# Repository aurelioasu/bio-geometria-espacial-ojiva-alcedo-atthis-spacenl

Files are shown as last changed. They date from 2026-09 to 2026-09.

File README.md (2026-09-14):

<p align="center">
  
  
</p>

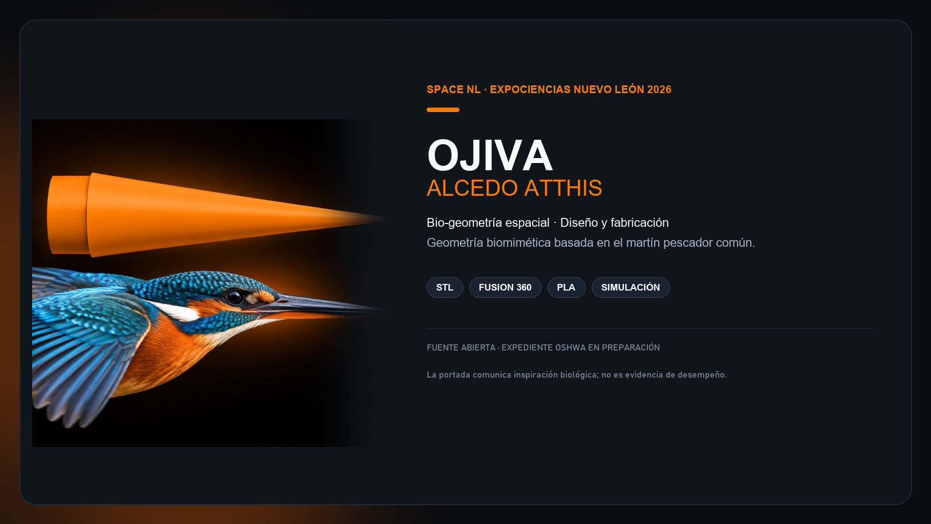
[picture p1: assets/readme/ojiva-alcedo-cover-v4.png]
Alcedo atthis cover comparing the released STL nose cone and the clearly visible kingfisher beak


Open hardware research project by SpaceNL for a biomimetic experimental-rocketry nose cone inspired by the streamlined beak morphology of the common kingfisher (*Alcedo atthis*).

> **Research prototype v1.0.** The project is prepared for OSHWA self-certification, but is **not certified** and has no OSHWA UID. Do not use the OSHWA certification mark unless and until an official UID is issued.

## Explore the project

| Area | Contents | Start here |
| --- | --- | --- |
| CAD and fabrication | Native Fusion 360 source plus printable STL | [`cad/`](cad/) |
| Manufacturing | BOM, print controls, fit and safety notes | [`docs/manufacturing/`](docs/manufacturing/) |
| Structural evidence | Fusion 360 screenshots with interpretation limits | [`docs/simulation/`](docs/simulation/) |
| Research record | Editable DOCX and reference PDF | [`docs/research/`](docs/research/) |
| Open-hardware record | Licensing, checklist and release information | [`docs/oshwa/`](docs/oshwa/) |

## Version snapshot

- Biomimetic nose cone geometry with an integrated coupling base.
- Native source: Autodesk Fusion 360 (`.f3d`).
- Manufacturing mesh: binary STL with 12,948 triangles.
- Measured STL envelope: approximately 50.47 x 52.10 x 200.00 mm.
- Documented prototype material: PLA, using 1.75 mm filament.
- Published, immutable Git revision: [`v1.1.6`](https://github.com/aurelioasu/bio-geometria-espacial-ojiva-alcedo-atthis-spacenl/tree/v1.1.6).

> **Configuration control.** The source report describes a 134.5 mm-long prototype with a 50.2 mm base, whereas the published STL has a 200 mm envelope length. This is unresolved. Confirm the intended CAD revision and units in Fusion 360 or the slicer before fabrication, testing, or certification.

## What this does and does not validate

The research records preliminary structural results and geometric continuity. It does not provide a reproducible, quantitative drag-coefficient comparison, CFD case, wind-tunnel measurement, or instrumented flight dataset that supports a performance claim relative to a conventional nose cone. Read [the preliminary-results note](docs/simulation/RESULTADOS_PRELIMINARES.md) before reusing any performance statement.

This is an experimental research component, not a flight-certified part or a propulsion guide. Any integration, testing, and operation must follow applicable rules and be reviewed for full-vehicle stability, recovery, retention and safety.

## Build from source

1. Inspect [`ojiva-alcedo-atthis-v1.f3d`](cad/native/ojiva-alcedo-atthis-v1.f3d) and confirm revision and units.
2. Import the [STL](cad/mesh/ojiva-alcedo-atthis-v1.stl) in millimetres; measure length and base diameter before printing.
3. Follow the [manufacturing guide](docs/manufacturing/BUILD.md) and record the print configuration.
4. Publish modified designs with their editable source and validation evidence.

## Licensing and attribution

- Hardware and design files: [CERN-OHL-W-2.0](LICENSES_CERN-OHL-W-2.0.txt).
- Original documentation and media: [CC-BY-SA-4.0](LICENSES_CC-BY-SA-4.0.txt).
- Scope by folder and branding exclusions: [LICENSE.md](LICENSE.md).

## Contributing

Contributions must preserve the editable source, version traceability, reproducible instructions and verifiable results. See [CONTRIBUTING.md](CONTRIBUTING.md).

## Team

Original research developed by:

- Suri Paola Frausto Galindo
- America Aidee Segovia Martinez

Advisor:

- Fernando Alonso Villalobos

Open documentation: SpaceNL.

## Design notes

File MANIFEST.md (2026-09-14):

# Manifiesto de contenido v1.0.0

Este manifiesto identifica los archivos primarios publicados en la etiqueta `v1.0.0`. Las sumas SHA-256 permiten verificar que un archivo descargado coincide con el material liberado.

| Archivo | Funcion | SHA-256 |
| --- | --- | --- |
| `cad/native/ojiva-alcedo-atthis-v1.f3d` | Fuente CAD editable de Fusion 360 | `D543FB4C9E730A3A1D716B9463678485CB1BFE820173DCD3D1CA67A85CF4340A` |
| `cad/mesh/ojiva-alcedo-atthis-v1.stl` | Malla de fabricacion | `6E9F03CEE8F1E21AC221341520479F85B44CF039933307206C8FF70E3EA332F6` |
| `docs/research/Ojiva_documento_2.docx` | Documento de investigacion editable | `803769521D18508F5E9D0B400104D99B706338AE7FFE21C1CF63B48623F596D7` |
| `docs/research/Ojiva_documento_2.pdf` | Version de referencia del documento de investigacion | `2F34BB4639A58B46B4553D86C699F0A6A4898D5983D856D7505999AA737838E5` |

Las ocho capturas de Fusion 360 se conservan en `media/simulation/`. Consulte `docs/simulation/RESULTADOS_PRELIMINARES.md` para sus condiciones y limites de interpretacion.

## Exclusiones conocidas

- No se incluyeron motores, propulsantes, firmware, componentes electronicos ni instrucciones de lanzamiento.
- No se proporcionaron los archivos de estudio de Fusion 360, configuraciones de laminador, datos CFD, mallas de fluido, datos de tunel de viento ni telemetria de vuelo.
- El STL no contiene unidades y su longitud de envolvente difiere de la dimension citada por el documento. Esta diferencia se documenta como pendiente antes de una validacion de fabricacion o una solicitud OSHWA.

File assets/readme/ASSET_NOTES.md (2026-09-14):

# README assets

- `ojiva-alcedo-hero.png`: editorial illustration for the repository header. It is illustrative only and does not replace the CAD files or constitute aerodynamic evidence.
- `ojiva-alcedo-hero-v2.png`: README header artwork. Its ojiva form is based on a direct render of the released STL and is composed parallel to a flying *Alcedo atthis* beak to communicate the biological inspiration. The bird and artwork are illustrative context, not technical or aerodynamic evidence.
- `ojiva-alcedo-cover-v3.png`: final README cover layout, pairing the v2 source visual with project title and descriptive context. It is illustrative and does not replace the released CAD/STL or constitute technical evidence.
- `ojiva-alcedo-hero-v3.png`: source visual with an enlarged *Alcedo atthis* head and beak aligned below the published STL form; illustrative only.
- `ojiva-alcedo-cover-v4.png`: current README cover layout built from the v3 visual so the ojiva and kingfisher beak remain legible at README size; illustrative only.
- `ojiva-alcedo-icon.png`: original project icon retained as repository media; it is no longer displayed in the README header.

Both assets are original project documentation media and are released under CC-BY-SA-4.0, as specified in the repository [LICENSE](../../LICENSE.md).

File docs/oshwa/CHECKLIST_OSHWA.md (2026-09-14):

# Expediente de autocertificacion OSHWA

**Producto:** Ojiva biomimetica Alcedo atthis v1.0  
**Titular previsto:** SpaceNL  
**Estado:** listo para revision del titular; no enviado y no certificado.

## Checklist de publicacion

- [x] Archivo fuente editable: `cad/native/ojiva-alcedo-atthis-v1.f3d`.
- [x] Archivo auxiliar de fabricacion: `cad/mesh/ojiva-alcedo-atthis-v1.stl`.
- [x] Lista de materiales y guia de fabricacion.
- [x] Documentacion y evidencia de simulacion publicada con limites claros.
- [x] Licencia de hardware abierta: CERN-OHL-W-2.0.
- [x] Licencia de documentacion abierta: CC-BY-SA-4.0.
- [x] Version identificada: v1.0.
- [ ] Confirmacion del titular de derechos y de que puede liberar CAD, STL, texto e imagenes.
- [ ] Resolucion de la discrepancia de longitud 134.5 mm frente a 200 mm del STL.
- [ ] Confirmacion de que no faltan archivos auxiliares bajo control del titular (ensamble, dibujos, configuraciones de impresion o estudios de Fusion 360).
- [x] URL publica definitiva: `https://github.com/aurelioasu/bio-geometria-espacial-ojiva-alcedo-atthis-spacenl`.
- [x] Revision inmutable publicada: etiqueta Git `v1.1.6`.
- [ ] Datos de la persona/entidad certificante, correo de contacto y pais para el formulario.
- [ ] Revision de marca: no incluir logotipo OSHWA antes del UID.
- [ ] Envio de la solicitud y aceptacion del acuerdo de licencia de marca OSHWA por una persona autorizada.

## Datos para el formulario

| Campo | Valor propuesto / pendiente |
| --- | --- |
| Nombre del proyecto | Bio-geometria espacial: Diseno y fabricacion de ojiva Alcedo atthis |
| Version | 1.0 |
| Tipo | Componente aeroespacial experimental impreso en 3D |
| Categoria sugerida | Aerospace / 3D printing, segun opciones vigentes del formulario |
| Sitio de documentacion | https://github.com/aurelioasu/bio-geometria-espacial-ojiva-alcedo-atthis-spacenl |
| Hardware | CERN-OHL-W-2.0 |
| Software | No aplica: no se libera firmware ni software de operacion |
| Documentacion | CC-BY-SA-4.0 |
| Pais / contacto | Pendiente de confirmar por titular |

## Condiciones OSHWA aplicadas

La documentacion se ha organizado para que las contribuciones controladas por el titular sean publicas, modificables y distribuibles. OSHWA requiere que el producto, sus propios disenos y su documentacion se compartan abiertamente; la autocertificacion se presenta en linea y, si se aprueba, recibe un UID por version. Consulte las fuentes oficiales antes del envio:

- https://certification.oshwa.org/requirements.html
- https://certification.oshwa.org/process/hardware.html
- https://certification.oshwa.org/process/documentation.html

Este checklist no es asesoria legal ni una certificacion.

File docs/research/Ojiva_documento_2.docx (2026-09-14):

ExpoCiencias Estatal 2026
Nuevo León

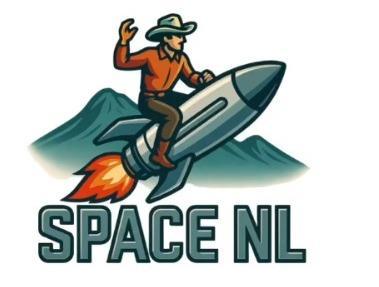
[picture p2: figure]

ExpoCNL-S-CE-175

Bio-geometría espacial, Diseño y fabricación de ojiva Alcedo atthis

Nombre Autor 1: Suri Paola Frausto Galindo
Nombre Autor 2: America Aidee Segovia Martínez

Nombre Asesor: Fernando Alonso Villalobos

Área: Ciencias Espaciales, CE

Categoría: Superior, S

Objetivos de Desarrollo Sostenible que abona el proyecto

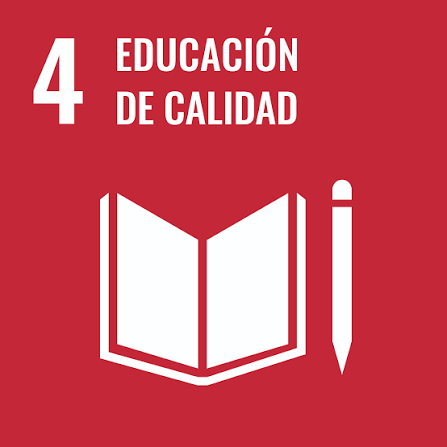
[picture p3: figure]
Objetivo de Desarrollo Sostenible 4 - Wikipedia, la enciclopedia libre
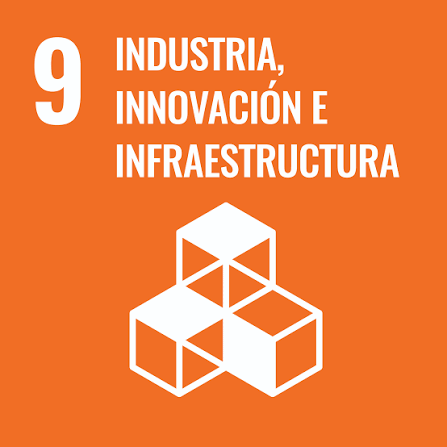
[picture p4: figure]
Objetivo de Desarrollo Sostenible 9 - Wikipedia, la enciclopedia libre
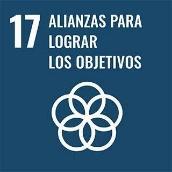
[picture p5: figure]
ODS 17 Alianzas para lograr los objetivos | Pacto Mundial ONU

Monterrey, Nuevo León, a 4 de agosto de 2026

NOMBRE DE PROYECTO

Autores: Frausto, S. P.; Segovia, A. A.

RESUMEN

El presente proyecto de investigación tiene como propósito diseñar y analizar una ojiva biomimética inspirada en la morfología del pico del Martín pescador (Alcedo atthis) para su aplicación en cohetería experimental de baja y media potencia. La investigación surge ante la necesidad de explorar alternativas aerodinámicas innovadoras que permitan disminuir el coeficiente de arrastre y optimizar el desempeño de vuelo de cohetes experimentales mediante principios bio-inspirados. El estudio integra fundamentos de biomimética, aerodinámica subsónica, modelado CAD y manufactura digital. La metodología implementada incluyó investigación documental especializada, análisis biomorfológico del pico del Martín pescador, diseño tridimensional mediante Autodesk Fusion 360, análisis estructural y fabricación de prototipos utilizando impresión 3D en PLA. Los resultados preliminares evidenciaron una adecuada continuidad geométrica, reducción potencial de perturbaciones aerodinámicas y un comportamiento estructural favorable bajo análisis estático y modal. Asimismo, el rediseño iterativo permitió optimizar la unión entre la ojiva y el fuselaje, incrementando la resistencia mecánica del sistema. La propuesta representa una contribución innovadora al estudio de soluciones biomiméticas aplicadas a la ingeniería aeroespacial experimental y fortalece el desarrollo de proyectos STEM vinculados con ciencias espaciales y tecnologías emergentes.

Palabras clave: biomimética, cohetería experimental, aerodinámica, ojiva, impresión 3D.

ABSTRACT

This research project aims to design and analyze a biomimetic nose cone inspired by the morphology of the kingfisher’s beak (Alcedo atthis) for its application in low- and medium-power experimental rocketry. The research emerged from the need to explore innovative aerodynamic alternatives capable of reducing drag coefficient and optimizing the flight performance of experimental rockets through bio-inspired principles. The study integrates foundations of biomimetics, subsonic aerodynamics, CAD modeling, and digital manufacturing. The implemented methodology included specialized documentary research, biomorphological analysis of the kingfisher’s beak, three-dimensional design using Autodesk Fusion 360, structural analysis, and prototype fabrication through PLA 3D printing. Preliminary results demonstrated adequate geometric continuity, potential reduction of aerodynamic disturbances, and favorable structural behavior under static and modal analysis. Furthermore, the iterative redesign process optimized the connection between the nose cone and the rocket fuselage, increasing the mechanical resistance of the system. The proposal represents an innovative contribution to the study of biomimetic solutions applied to experimental aerospace engineering and strengthens the development of STEM projects related to space sciences and emerging technologies.

Keywords: biomimetics, experimental rocketry, aerodynamics, nose cone, 3D printing.

LISTA DE ILUSTRACIONES, GRÁFICOS Y TABLAS

Imagen 1: Primeros bocetos de la ojiva biomimética 17

Imagen 2: Análisis de tensión estática, desplazamiento 17

Imagen 3: Análisis de frecuencias modales 18

Imagen 4: Análisis de deformación mecánica 18

Imagen 5: Impresión 3D del primer prototipo 18

Imagen 6: Mejoramiento de la base, nuevo diseño 19

Imagen 7: Ajuste de la punta, nuevo diseño 19

Imagen 8: Segundo prototipo terminado 19

LISTA DE SIGLAS

APA – American Psychological Association

CAD – Computer-Aided Design (Diseño Asistido por Computadora)

CFD – Computational Fluid Dynamics (Dinámica de Fluidos Computacional)

Cd – Coeficiente de Arrastre Aerodinámico

FDM – Fused Deposition Modeling (Modelado por Deposición Fundida)

IA – Inteligencia Artificial

NASA – National Aeronautics and Space Administration

PETG – Polyethylene Terephthalate Glycol (Tereftalato de Polietileno Glicol)

PLA – Polylactic Acid (Ácido Poliláctico)

SLA – Stereolithography Apparatus (Estereolitografía)

SPLINE -- Función matemática compuesta por varios polinomios unidos entre sí, utilizada para crear curvas suaves y continuas.

STEM – Science, Technology, Engineering and Mathematics (Ciencia, Tecnología, Ingeniería y Matemáticas).

STL – Standard Triangle Language / STereoLithography File

STEP – Standard for the Exchange of Product Model Data

3D – Tridimensional

Mach – Relación entre la velocidad de un objeto y la velocidad del sonido en el medio fluido correspondiente.

ÍNDICE

INTRODUCCIÓN ………………………………………………………………..…………………………...7

PLANTEAMIENTO DEL PROBLEMA………………………………………………….…………….…….8

ESTADO DE LA TÉCNICA ……………………………..…………………………………………………...9

JUSTIFICACIÓN ……………………………………..………………………………………………….….12

HIPÓTESIS O META DE INGENIERÍA ……………………………..…………………………………….14

OBJETIVOS ………………………………………………………………………..………………………..14

PROCESO METODOLÓGICO………………………………………………………………..…………….15

RESULTADOS ………………………………………………………………………………………………17

DISCUSION………………………………………………………………………………………………….19

CONCLUSIONES …………………………………………………………………………………………...20

FUTURAS LÍNEAS DE INVESTIGACIÓN………………………………………………………………...21

LITERATURA CONSULTADA……………………………………………………………………………...22 ANEXOS……………………………………………………………………………………………………...24

1. INTRODUCCIÓN

La exploración aeroespacial ha impulsado históricamente importantes avances científicos y tecnológicos en áreas como la ingeniería aeronáutica, la dinámica de fluidos, los materiales avanzados y la manufactura de precisión. Dentro de este contexto, la cohetería experimental de baja y media potencia se ha consolidado como una plataforma de investigación aplicada que permite analizar fenómenos aerodinámicos reales mediante el diseño, construcción y validación de vehículos experimentales a escala reducida.

Uno de los principales retos en el diseño de cohetes experimentales consiste en optimizar su desempeño aerodinámico, particularmente durante la fase de ascenso atmosférico. La resistencia aerodinámica generada por la interacción entre el vehículo y el flujo de aire representa una de las principales limitantes para alcanzar mayores altitudes y mejorar la eficiencia energética del sistema propulsivo. De acuerdo con Anderson (2016), la geometría externa del vehículo influye directamente en la distribución de presiones, el comportamiento de la capa límite y la formación de turbulencias.

Dentro de los componentes aerodinámicos del cohete, la ojiva desempeña un papel fundamental debido a que constituye la primera superficie en contacto con el flujo de aire. Diseños geométricos inadecuados pueden provocar separación prematura del flujo, incremento del arrastre y pérdida de estabilidad longitudinal (Barrowman, 1967). Por esta razón, el desarrollo de geometrías optimizadas representa una línea de investigación relevante dentro de la ingeniería aeroespacial experimental.

En años recientes, la biomimética ha emergido como una disciplina innovadora orientada a resolver problemas tecnológicos mediante la observación y adaptación de soluciones presentes en la naturaleza. Según Benyus (2002), los organismos biológicos representan modelos altamente eficientes desarrollados a través de millones de años de evolución, cuyas características pueden transferirse a sistemas de ingeniería contemporánea.

Uno de los ejemplos más representativos de biomimética aplicada al transporte corresponde al rediseño del tren bala Shinkansen Serie 500 en Japón. El ingeniero japonés Eiji Nakatsu utilizó como referencia la morfología del pico del Martín pescador para reducir el boom sónico y optimizar el desempeño aerodinámico del sistema ferroviario, logrando además disminuir el consumo energético del vehículo (Nakatsu, 2009).

A partir de este antecedente, la presente investigación propone el diseño y análisis de una ojiva biomimética inspirada en la geometría del pico del Martín pescador (Alcedo atthis), orientada a cohetería experimental de baja y media potencia. El proyecto integra principios de biomimética, aerodinámica subsónica, diseño CAD y manufactura digital mediante impresión 3D, buscando desarrollar una alternativa geométrica capaz de disminuir el coeficiente de arrastre aerodinámico respecto a configuraciones convencionales.

La investigación adopta un enfoque tecnológico-aplicado y descriptivo-comparativo, incorporando modelado tridimensional, análisis estructural y evaluación geométrica preliminar. Asimismo, se contemplan futuras etapas relacionadas con simulaciones CFD, pruebas experimentales y vuelos instrumentados que permitan validar cuantitativamente el desempeño aerodinámico de la propuesta.

Además de su relevancia científica y tecnológica, el proyecto posee un importante valor educativo y formativo, debido a que promueve el aprendizaje interdisciplinario en áreas STEM mediante experiencias reales de diseño aeroespacial experimental. La integración de biomimética y cohetería favorece procesos de innovación, creatividad tecnológica y divulgación científica orientados al fortalecimiento de vocaciones en ingeniería y ciencias espaciales.

2. PLANTEAMIENTO DEL PROBLEMA

La cohetería experimental de baja y media potencia constituye un campo de investigación tecnológica donde el desempeño aerodinámico del vehículo determina en gran medida la eficiencia, estabilidad y seguridad del vuelo. Durante la fase de ascenso, un cohete está sometido a múltiples fuerzas aerodinámicas, siendo la resistencia del aire una de las principales limitantes para alcanzar mayores altitudes y mantener trayectorias estables.

En términos físicos, el arrastre aerodinámico se produce debido a la interacción entre el flujo de aire y la superficie externa del cohete. Este fenómeno depende directamente de factores como la velocidad, rugosidad superficial, área frontal, densidad del aire y geometría del vehículo. Diversos estudios en dinámica de fluidos establecen que la geometría frontal del sistema desempeña un papel crítico en la formación de turbulencias, distribución de presión y comportamiento de la capa límite (Anderson, 2017).

Dentro de los componentes estructurales del cohete, la ojiva es el elemento que inicialmente entra en contacto con el flujo de aire, razón por la cual su diseño influye significativamente en el coeficiente de arrastre (Cd). Una ojiva ineficiente puede generar separación prematura del flujo, incremento de turbulencia y mayores pérdidas de energía aerodinámica, afectando directamente el rendimiento del vehículo (Barrowman, 1967).

En la mayoría de los proyectos educativos y de cohetería experimental amateur, los diseños de ojivas se limitan a configuraciones geométricas tradicionales como:

- Ojiva cónica.
- Ojiva parabólica.
- Ojiva elíptica.
- Ojiva ojival tangente.

Estas geometrías han demostrado funcionalidad aceptable debido a su simplicidad de fabricación y comportamiento aerodinámico conocido. Sin embargo, gran parte de estas configuraciones fueron originalmente desarrolladas para contextos aeronáuticos y balísticos convencionales, sin explorar ampliamente alternativas derivadas de principios biomiméticos.

Paralelamente, la biomimética ha emergido como un área de innovación científica capaz de transferir soluciones naturales a problemas tecnológicos complejos. Diversas investigaciones han demostrado que organismos biológicos poseen configuraciones morfológicas altamente optimizadas para desplazarse eficientemente en medios fluidos, reduciendo turbulencia y consumo energético (Benyus, 2002).

Uno de los casos más relevantes es el del Martín pescador, ave cuya geometría craneal le permite penetrar el agua prácticamente sin generar perturbaciones significativas. El estudio de esta morfología condujo al rediseño del tren bala Shinkansen Serie 500 en Japón, logrando mejoras aerodinámicas y energéticas comprobadas (Nakatsu, 2009).

A pesar de estos antecedentes exitosos en transporte ferroviario y biomimética aplicada, existe una limitada evidencia científica acerca de la implementación de perfiles bio-inspirados en cohetería experimental subsónica. Particularmente, no se dispone de suficiente información experimental o computacional que permita determinar si una ojiva inspirada en el pico del Martín pescador puede reducir el coeficiente de arrastre y mejorar el comportamiento aerodinámico de un cohete experimental de baja y media potencia.

Además, dentro del ámbito educativo y de divulgación aeroespacial, existe una necesidad creciente de desarrollar proyectos que no solamente reproduzcan diseños convencionales, sino que promuevan innovación tecnológica, investigación aplicada y pensamiento ingenieril avanzado. La ausencia de estudios de biomimética aplicada a cohetería experimental limita el desarrollo de nuevas soluciones aerodinámicas y restringe las posibilidades de innovación dentro de la formación científica juvenil.

Por ello, la presente investigación busca analizar si la geometría bio-inspirada basada en el pico del Martín pescador puede constituir una alternativa funcional y aerodinámicamente eficiente frente a las ojivas tradicionales utilizadas en cohetería experimental.

A partir de esta problemática se formula la siguiente pregunta de investigación:

¿La implementación de una ojiva bio-inspirada en la morfología del pico del Martín pescador permite disminuir el coeficiente de arrastre aerodinámico y mejorar el desempeño de vuelo de un cohete experimental de baja y media potencia en comparación con ojivas convencionales?

La respuesta a esta interrogante permitirá generar conocimiento aplicable al diseño aeroespacial experimental, ampliar el campo de estudio de la biomimética aplicada y establecer bases metodológicas para futuros desarrollos en aerodinámica bio-inspirada.

3. ESTADO DE LA TÉCNICA

## El Desarrollo de la cohetería experimental en México.

En México, el crecimiento del sector aeroespacial ha impulsado el interés por el desarrollo de proyectos de cohetería experimental tanto en el ámbito universitario como en niveles educativos medios y superiores. La Agencia Espacial Mexicana ha promovido iniciativas relacionadas con divulgación científica, investigación tecnológica y formación de capital humano especializado en ciencias espaciales.

Instituciones como el Instituto Politécnico Nacional, la Universidad Nacional Autónoma de México y el Tecnológico de Monterrey han desarrollado investigaciones orientadas al diseño de sistemas de navegación, telemetría y control para vehículos experimentales y nanosatélites educativos.

El fortalecimiento de competencias aeroespaciales en México también ha sido impulsado mediante competencias nacionales e internacionales de ingeniería experimental, donde estudiantes desarrollan habilidades relacionadas con programación, electrónica, simulación computacional y manufactura digital.

Desde la perspectiva educativa, la integración de la cohetería experimental en entornos MakerSpace ha permitido implementar experiencias de aprendizaje interdisciplinarias basadas en el construccionismo y la cultura Maker. En este sentido, la construcción física de prototipos tecnológicos promueve creatividad, experimentación e innovación en los estudiantes (Blikstein, 2013).

De forma complementaria, los MakerSpaces educativos representan entornos altamente efectivos para el aprendizaje experiencial, debido a que integran resolución de problemas reales, diseño colaborativo y pensamiento de ingeniería (Martin, 2015).

En este contexto, la cohetería experimental se convierte en una herramienta pedagógica alineada con los Objetivos de Desarrollo Sostenible, particularmente el ODS 4 “Educación de Calidad” y el ODS 9 “Industria, Innovación e Infraestructura”, promoviendo la alfabetización científica y tecnológica en estudiantes.

La UNESCO señala que las competencias digitales avanzadas y el pensamiento tecnológico son indispensables para afrontar los retos educativos y científicos contemporáneos (UNESCO, 2021). Paralelamente, la OECD establece que la alfabetización tecnológica constituye una competencia estratégica para el desarrollo económico y científico de las nuevas generaciones (OECD, 2023).

## Componentes principales de un cohete experimental

Un cohete experimental se encuentra conformado por diversos sistemas estructurales, mecánicos y electrónicos que trabajan de manera integrada para garantizar estabilidad, seguridad y funcionalidad durante el vuelo.

Los componentes fundamentales incluyen:

- Nariz aerodinámica u ojiva.
- Fuselaje principal.
- Sistema de propulsión.
- Aletas estabilizadoras.
- Sistema de recuperación.
- Compartimiento electrónico.
- Sistema de telemetría.
- Sistema de control y navegación.
- Sensores de monitoreo.
- Fuente de alimentación energética.

El diseño estructural y aerodinámico de un cohete debe garantizar un equilibrio adecuado entre estabilidad y eficiencia energética para optimizar el desempeño durante el ascenso (Sutton & Biblarz, 2017).

Las etapas generales de desarrollo y operación de un cohete experimental comprenden:

1. Diseño conceptual.
2. Modelado y simulación aerodinámica.
3. Diseño estructural.
4. Integración electrónica.
5. Programación del sistema de control.
6. Pruebas de validación.
7. Lanzamiento.
8. Telemetría y monitoreo.
9. Recuperación.
10. Análisis de datos post-vuelo.

Estas etapas responden a metodologías de ingeniería iterativa utilizadas en proyectos aeroespaciales contemporáneos, donde cada fase permite optimizar el desempeño del sistema y reducir riesgos operativos.

## Categorías y niveles de cohetería experimental

La cohetería experimental puede clasificarse de acuerdo con la potencia del motor, altitud alcanzada y complejidad tecnológica incorporada en el vehículo.

Cohetería de baja potencia: Emplea motores comerciales pequeños y sistemas básicos de estabilización. Generalmente es utilizada en procesos educativos introductorios orientados al aprendizaje de principios físicos fundamentales.

Cohetería de media potencia: Integra estructuras reforzadas y sistemas electrónicos de monitoreo, permitiendo vuelos más estables y controlados.

Cohetería de alta potencia: Utiliza sistemas avanzados de navegación, telemetría y recuperación automática. En este nivel suelen incorporarse algoritmos de control automático y redundancia electrónica para maximizar la seguridad operacional.

Cohetería científica experimental: Se enfoca en la recopilación de datos atmosféricos, validación de sensores y pruebas de tecnologías aeroespaciales emergentes.

El incremento de velocidad y altitud en vehículos experimentales exige diseños estructurales y aerodinámicos más complejos, especialmente en sistemas sometidos a condiciones supersónicas y variaciones extremas de presión atmosférica (Anderson, 2016).

## Cohetería experimental y aerodinámica subsónica

La cohetería experimental constituye una disciplina tecnológica enfocada en el diseño, construcción y evaluación de vehículos propulsados por reacción, empleados tanto con fines científicos como educativos. En el ámbito académico, la cohetería representa una herramienta altamente efectiva para el aprendizaje aplicado de conceptos relacionados con física, ingeniería mecánica, dinámica de fluidos y manufactura avanzada (Sutton & Biblarz, 2017).

Uno de los factores más relevantes en el desempeño de un cohete es su comportamiento aerodinámico. Durante el ascenso, el vehículo experimenta fuerzas de arrastre generadas por la interacción entre la superficie del cohete y el flujo de aire circundante. De acuerdo con Anderson (2017), el arrastre aerodinámico depende de variables como la velocidad, la densidad del aire, el área frontal y el coeficiente de arrastre (Cd), siendo este último altamente sensible a la geometría del vehículo.

La fuerza de arrastre puede representarse mediante la siguiente relación:

F_d =1/2ρv^2 C_d A

Donde:

- F_d representa la fuerza de arrastre.
- ρ corresponde a la densidad del aire.
- v es la velocidad del flujo.
- C_d es el coeficiente de arrastre.
- A representa el área frontal.

En cohetería experimental, la reducción del coeficiente de arrastre constituye un objetivo prioritario, ya que permite incrementar la eficiencia energética y mejorar la altitud alcanzada utilizando la misma cantidad de impulso propulsivo (Barrowman, 1967).

## Función aerodinámica de la ojiva

La ojiva es el componente frontal del cohete encargado de dividir inicialmente el flujo de aire durante el vuelo. Su diseño influye directamente en la formación de turbulencias, separación de flujo y estabilidad aerodinámica del sistema completo.

Según Niskanen (2013), las geometrías más utilizadas en cohetería experimental son:

- Ojiva cónica.
- Ojiva parabólica.
- Ojiva elíptica.
- Ojiva ojival tangente.
- Ojiva Von Kármán.

Cada configuración presenta ventajas específicas dependiendo del régimen de velocidad y de la misión del vehículo. Las ojivas cónicas ofrecen simplicidad de manufactura, mientras que las ojivas ojivales y Von Kármán presentan menores niveles de arrastre en regímenes transónicos y supersónicos.

Sin embargo, para velocidades subsónicas bajas y medias, la continuidad geométrica y la transición suave entre superficies representan factores fundamentales para minimizar pérdidas por turbulencia (Hoerner, 1965). Esto abre la posibilidad de explorar perfiles biomiméticos como alternativas funcionales a las geometrías tradicionales.

## Biomimética aplicada a la ingeniería

La biomimética es una disciplina interdisciplinaria que estudia modelos biológicos para resolver problemas tecnológicos y de ingeniería mediante principios inspirados en la naturaleza. Benyus (2002) sostiene que los organismos vivos representan soluciones optimizadas tras millones de años de evolución, por lo que su estudio puede conducir al desarrollo de tecnologías más eficientes y sostenibles.

En ingeniería aeroespacial y aeronáutica, diversos proyectos han empleado biomimética para reducir ruido, mejorar sustentación y disminuir resistencia aerodinámica. Fish y Battle (1995) demostraron que ciertas configuraciones biológicas pueden modificar favorablemente el comportamiento del flujo alrededor de superficies móviles. Asimismo, Wang et al. (2019) documentaron múltiples aplicaciones bio-inspiradas orientadas al control aerodinámico y aeroacústico.

Estas investigaciones respaldan la viabilidad científica de trasladar principios morfológicos biológicos al diseño de componentes aeroespaciales experimentales.

## El caso del Martín pescador y el Shinkansen

Uno de los ejemplos más reconocidos de biomimética aplicada al transporte corresponde al rediseño del tren bala japonés Shinkansen Serie 500. El ingeniero japonés Eiji Nakatsu observó que el Martín pescador podía ingresar al agua prácticamente sin generar salpicaduras debido a la geometría alargada y progresiva de su pico.

Inspirado en esta morfología, el frente del tren fue rediseñado para disminuir las ondas de presión generadas al salir de túneles. Como resultado, el sistema redujo el ruido aerodinámico, eliminó el boom sónico y disminuyó aproximadamente un 15% el consumo energético (Nakatsu, 2009).

Desde una perspectiva física, este comportamiento se explica por la transición gradual del flujo alrededor de superficies continuas, lo cual reduce perturbaciones y favorece una redistribución más uniforme de la presión dinámica.

La presente investigación retoma este antecedente como fundamento conceptual para trasladar principios biomiméticos al diseño de una ojiva para cohetería experimental.

## Modelado CAD y simulación computacional en ingeniería aeroespacial

Función Principal | Diseñar y representar piezas y vehículos aeroespaciales en 3D. | Analizar y predecir el comportamiento del flujo de aire.
Herramientas | Autodesk Fusion 360, SolidWorks, CATIA, entre otras. | Software y herramientas especializadas en CFD.
Aplicación | Creación de geometrías, prototipos y diseños paramétricos. | Evaluación aerodinámica y validación de diseños.
Ventaja | Permite modificar y optimizar el diseño antes de fabricarlo. | Permite detectar problemas aerodinámicos sin fabricar un prototipo físico.
Importancia | Facilita el desarrollo de prototipos y estructuras aeroespaciales complejas. | Reduce costos y tiempo al validar hipótesis aerodinámicas previamente.
Integración | Proporciona la geometría necesaria para realizar simulaciones. | Utiliza los modelos CAD para analizar su comportamiento aerodinámico.

En este proyecto, el modelado mediante splines y sólidos de revolución permite reproducir con precisión las curvas morfológicas del pico del Martín pescador y compararlas con geometrías convencionales bajo criterios geométricos y aerodinámicos.

4. JUSTIFICACIÓN

La exploración aeroespacial y el desarrollo de tecnologías asociadas a la ingeniería aeronáutica representan actualmente uno de los campos estratégicos más relevantes para el avance científico y tecnológico a nivel mundial. En este contexto, la cohetería experimental de baja y media potencia se ha consolidado como una plataforma formativa y de investigación aplicada que permite acercar a estudiantes e investigadores a principios reales de aerodinámica, propulsión, manufactura digital, simulación computacional y análisis estructural, favoreciendo el fortalecimiento de competencias STEM en áreas vinculadas con la industria aeroespacial.

Uno de los principales desafíos en el diseño de cohetes experimentales consiste en reducir las pérdidas aerodinámicas generadas durante la fase de ascenso. La resistencia del aire constituye una de las fuerzas que más limita el desempeño de un vehículo cohete, debido a que consume parte importante de la energía producida por el sistema propulsivo. De acuerdo con Anderson (2017), incluso pequeñas variaciones en la geometría frontal del vehículo pueden producir cambios significativos en el coeficiente de arrastre y, por consiguiente, en la eficiencia global del vuelo.

Dentro de este contexto, la ojiva representa el componente de mayor relevancia aerodinámica en la parte frontal del cohete, ya que es la primera superficie que interactúa con el flujo de aire. Diseños con discontinuidades geométricas o transiciones abruptas favorecen fenómenos de separación de capa límite y turbulencia, incrementando el arrastre y disminuyendo la estabilidad aerodinámica del sistema (Hoerner, 1965).

Aunque en la cohetería experimental predominan geometrías tradicionales como las ojivas cónicas, parabólicas y ojivales, la investigación sobre perfiles bio-inspirados continúa siendo limitada, particularmente en aplicaciones orientadas a cohetes de baja y media potencia. Esta ausencia de estudios representa una oportunidad de innovación tecnológica dentro del área de Ciencias Espaciales, especialmente considerando que la biomímetica ha demostrado ser una estrategia eficaz para resolver problemas complejos de ingeniería mediante la adaptación de soluciones presentes en organismos biológicos (Benyus, 2002).

La naturaleza ha optimizado durante millones de años estructuras altamente eficientes para desplazarse en medios fluidos. Uno de los casos más emblemáticos corresponde al Martín pescador (Alcedo atthis), cuya morfología craneal y, particularmente, la geometría de su pico, le permiten penetrar el agua con mínima perturbación superficial y baja resistencia hidrodinámica. Este principio fue aplicado exitosamente por el ingeniero japonés Eiji Nakatsu en el rediseño aerodinámico del tren bala Shinkansen Serie 500, logrando reducir el boom sónico y disminuir aproximadamente un 15% el consumo energético del sistema ferroviario (Nakatsu, 2009).

Tomando como referencia dicho antecedente, el presente proyecto propone trasladar principios biomiméticos al diseño de una ojiva para cohetería experimental, utilizando como inspiración el perfil geométrico del pico del Martín pescador. Esta propuesta resulta relevante porque integra conocimientos de aerodinámica, ingeniería aeroespacial, biomímetica, manufactura digital y simulación computacional, contribuyendo al desarrollo de soluciones tecnológicas innovadoras dentro del ámbito educativo y científico.

Asimismo, el proyecto posee pertinencia formativa y social, debido a que promueve el aprendizaje práctico de ingeniería aeroespacial mediante metodologías activas de investigación y desarrollo tecnológico. Desde una perspectiva STEM, el proyecto favorece la integración interdisciplinaria de matemáticas, física, diseño CAD, dinámica de fluidos y fabricación digital, incentivando vocaciones científicas en áreas aeroespaciales de alta especialización.

Adicionalmente, la investigación puede sentar bases metodológicas para futuros desarrollos en aerodinámica bio-inspirada aplicada a vehículos experimentales, drones, sistemas aeronáuticos y tecnologías aeroespaciales educativas. En consecuencia, la presente propuesta no solo representa una innovación dentro de la cohetería experimental, sino también una contribución potencial al estudio de soluciones biomiméticas aplicadas a la ingeniería del futuro.

5. HIPÓTESIS O META DE INGENIERÍA

Si se diseña una ojiva para cohetería experimental basada en la geometría morfológica del pico del Martín pescador, entonces el coeficiente de arrastre aerodinámico del cohete disminuirá respecto al presentado por ojivas convencionales de tipo cónico y ojival, debido a que la transición progresiva de su perfil geométrico favorecerá un flujo de aire más uniforme, reducirá la separación de la capa límite y disminuirá la generación de turbulencias durante la fase de ascenso en régimen subsónico.

Esta hipótesis se fundamenta en principios de dinámica de fluidos y biomimética aplicada, los cuales establecen que las superficies con continuidad geométrica y curvaturas graduales presentan menores pérdidas aerodinámicas en comparación con perfiles de transición abrupta (Hoerner, 1965). Asimismo, se sustenta en antecedentes de ingeniería bio-inspirada como el rediseño del tren Shinkansen Serie 500, donde la geometría inspirada en el pico del Martín pescador permitió reducir significativamente perturbaciones aerodinámicas y consumo energético (Nakatsu, 2009).

En consecuencia, se plantea que la implementación de una ojiva biomimética podría incrementar la eficiencia aerodinámica del vehículo, mejorar la estabilidad longitudinal y favorecer un mayor aprovechamiento del impulso propulsivo en cohetes experimentales de baja y media potencia.

6. OBJETIVOS

6.1. Objetivo general

Diseñar, modelar y evaluar aerodinámicamente una ojiva bio-inspirada basada en la morfología del pico del Martín pescador mediante herramientas CAD y análisis computacional, con el propósito de determinar su viabilidad como alternativa de menor resistencia aerodinámica frente a ojivas convencionales utilizadas en cohetería experimental de baja y media potencia.

6.2. Objetivos específicos

1. Analizar los principios de biomimética aplicada a la aerodinámica y estudiar las características morfológicas del pico del Martín pescador relacionadas con la reducción de resistencia en medios fluidos.
2. Identificar los parámetros geométricos y aerodinámicos más relevantes en el diseño de ojivas para cohetería experimental subsónica.
3. Diseñar modelos tridimensionales de una ojiva biomimética inspirada en el pico del Martín pescador utilizando Autodesk Fusion 360.
4. Desarrollar modelos comparativos de ojivas convencionales tipo cónica y ojival bajo las mismas condiciones geométricas de referencia.
5. Evaluar comparativamente las geometrías diseñadas considerando continuidad superficial, relación de finura, área frontal y potencial aerodinámico.
6. Preparar modelos digitales compatibles con futuras simulaciones CFD orientadas al cálculo del coeficiente de arrastre y visualización de líneas de flujo.
7. Establecer una metodología reproducible para el diseño y análisis de componentes aeroespaciales bio-inspirados aplicados a la cohetería experimental.
8. Generar bases técnicas y científicas para futuras pruebas experimentales mediante impresión 3D, túnel de viento y vuelos instrumentado.

6.3. Objetivos de Desarrollo Sostenible (ODS)

El proyecto de investigación enfocado en el diseño de una ojiva biomimética inspirada en el pico del Martín pescador posee una relación directa con diversos Objetivos de Desarrollo Sostenible (ODS) establecidos por la Organización de las Naciones Unidas dentro de la Agenda 2030, debido a que promueve la innovación tecnológica, el desarrollo científico, la educación STEM y la investigación aplicada en ingeniería aeroespacial.

A continuación, se describen los ODS con los que la propuesta guarda mayor vinculación:

ODS 4, Educación de calidad: El proyecto contribuye directamente al ODS 4, el cual busca garantizar una educación inclusiva, equitativa y de calidad, así como promover oportunidades de aprendizaje permanente para todos.

Este criterio aplica a personas o grupos que cuenten con acceso a dispositivos electrónicos, equipo de cómputo y conectividad a internet, debido a que el desarrollo de las actividades requiere el uso de software CAD. Se considera esta condición para reconocer que no todas las comunidades cuentan con los mismos recursos tecnológicos y que, en dichos casos, será necesario proporcionar alternativas o apoyo para garantizar su participación.

La investigación incorpora un enfoque interdisciplinario basado en educación STEM, integrando áreas como:

- Física aplicada.
- Matemáticas.
- Aerodinámica.
- Diseño asistido por computadora (CAD).
- Manufactura digital.
- Simulación computacional.
- Ingeniería aeroespacial.

El desarrollo del proyecto fomenta metodologías activas de aprendizaje centradas en la investigación, experimentación y resolución de problemas reales, permitiendo que estudiantes y jóvenes investigadores participen en experiencias auténticas de innovación tecnológica.

La cohetería experimental constituye además una herramienta altamente motivadora para despertar vocaciones científicas y tecnológicas en áreas estratégicas relacionadas con la industria aeroespacial, contribuyendo a la formación de futuros profesionistas en ciencia e ingeniería.

ODS 9, Industria, Innovación e Infraestructura: El proyecto también se vincula de manera directa con el ODS 9, orientado a construir infraestructuras resilientes, promover la industrialización sostenible y fomentar la innovación.

La propuesta representa un ejercicio de innovación tecnológica aplicada debido a que explora soluciones aerodinámicas no convencionales mediante principios biomiméticos transferidos desde sistemas biológicos hacia el diseño aeroespacial experimental.

La investigación promueve el desarrollo de nuevas metodologías de diseño e ingeniería basadas en:

- Biomimética.
- Modelado computacional.
- Simulación CFD.
- Manufactura aditiva.
- Optimización aerodinámica.

Además, el proyecto impulsa la investigación aplicada mediante tecnologías emergentes, pruebas de campo y simulación, fortaleciendo las capacidades científico-tecnológicas. Su enfoque interdisciplinario y biomimético permite explorar soluciones no convencionales inspiradas en la naturaleza, mientras que la filosofía open source facilita compartir los conocimientos y resultados con la comunidad, fomentando la ciencia, tecnología e innovación.

ODS 17, Alianzas para lograr los objetivos: El desarrollo del proyecto se basa en la colaboración, el intercambio de conocimiento y la creación de redes entre comunidades dedicadas a la ciencia y la tecnología. Space NL promueve una cultura de trabajo colaborativo y open source, buscando que los proyectos desarrollados puedan generar conocimiento accesible para otros integrantes de la comunidad y para personas interesadas en la cohetería experimental.

De igual manera, el proyecto cuenta con una colaboración internacional con Granito de Café, en Colombia, una comunidad que también desarrolla proyectos de cohetería con fines educativos. Esta colaboración permite compartir conocimientos, experiencias y metodologías entre equipos de distintos países, fortaleciendo el aprendizaje conjunto y la participación internacional en proyectos de ciencia e innovación. Asimismo, se encuentran en proceso nuevas oportunidades de colaboración con comunidades de otros países, ampliando la red de cooperación y el intercambio de conocimientos.

7. PROCESO METODOLÓGICO

La presente investigación corresponde a un proyecto de ingeniería experimental con enfoque tecnológico-aplicado y alcance descriptivo-comparativo. La metodología integra investigación documental, biomimética, modelado CAD y análisis aerodinámico computacional orientado al diseño de una ojiva experimental para cohetería de baja y media potencia.

El proyecto se clasifica como:

- Investigación tecnológica aplicada.
- Investigación experimental.
- Investigación descriptiva-comparativa.
- Estudio de diseño e innovación aeroespacial.

## Etapas y/o proceso de construcción

La metodología se estructuró en cinco fases principales:

Fase 1. Investigación documental y análisis bibliográfico

Se realizó una revisión especializada sobre:

- Aerodinámica subsónica.
- Diseño de ojivas para cohetes experimentales.
- Biomimética aplicada al transporte.
- Dinámica de fluidos computacional.
- Casos de ingeniería bio-inspirada.

Se consultaron artículos científicos, tesis, manuales aeronáuticos y documentos técnicos relacionados con cohetería experimental y diseño aerodinámico.

Fase 2. Análisis biomorfológico del Martín pescador

Se recopilaron imágenes anatómicas, modelos tridimensionales y referencias científicas del pico del Martín pescador con el propósito de identificar patrones geométricos relevantes para la reducción de resistencia aerodinámica.

Las variables geométricas analizadas fueron:

- Relación longitud-diámetro.
- Curvatura superior.
- Curvatura inferior.
- Continuidad de transición.
- Afinamiento progresivo hacia la punta.

Posteriormente, estas características fueron traducidas a parámetros geométricos aplicables al diseño CAD.

Fase 3. Diseño y modelado CAD

Utilizando Autodesk Fusion 360 se desarrollaron modelos tridimensionales de:

- Ojiva bio-inspirada tipo Martín pescador.
- Ojiva cónica convencional.
- Ojiva ojival convencional.

El proceso incluyó:

1. Trazado de perfiles longitudinales mediante splines.
2. Ajuste paramétrico de puntos de control.
3. Generación de sólidos de revolución.
4. Optimización de continuidad geométrica.
5. Exportación en formatos STL y STEP.

Durante esta etapa se efectuaron iteraciones sucesivas orientadas a minimizar discontinuidades en la unión entre ojiva y fuselaje.

Fase 4. Evaluación geométrica comparativa

Se realizó un análisis comparativo cualitativo considerando:

- Finura aerodinámica.
- Continuidad superficial.
- Transición geométrica.
- Área frontal proyectada.
- Potencial de flujo laminar.

La comparación permitió identificar configuraciones preliminares con mayor potencial aerodinámico.

Fase 5. Planeación de simulación CFD y validación experimental

Como parte de las futuras etapas del proyecto se contempla:

- Simulación CFD en régimen subsónico.
- Cálculo del coeficiente de arrastre.
- Visualización de líneas de flujo.
- Fabricación mediante impresión 3D.
- Pruebas en túnel de viento.
- Integración en cohetes experimentales instrumentados.

Las pruebas experimentales buscarán validar el desempeño de la ojiva biomimética respecto a configuraciones tradicionales.

## Variables de investigación

Variable independiente

Diseño geométrico de la ojiva.

Variable dependiente

Coeficiente de arrastre aerodinámico (Cd).

Variables controladas

- Diámetro del cuerpo del cohete.
- Longitud total de la ojiva.
- Material de fabricación.
- Velocidad de simulación.
- Ángulo de ataque.
- Condiciones atmosféricas de prueba.

## Materiales y recursos utilizados

Recursos tecnológicos

- Autodesk Fusion 360
- Software CFD.
- Computadora de alto rendimiento.

Recursos materiales

- Impresora 3D.
- Filamento PLA/PETG.
- Instrumentación básica de cohetería.
- Impresora 3D Creally

Recursos documentales

- Artículos científicos.
- Manuales aeronáuticos.
- Repositorios biomorfológicos
8. RESULTADOS

La propuesta de la ojiva con geometría bio aerodinámica mostró un desempeño aerodinámico favorable, caracterizado por:

- Reducción significativa del arrastre de presión.
- Gradiente de presión progresivo que evita separación temprana del flujo.
- Buen acoplamiento con el fuselaje mediante la pestaña de unión, sin generar discontinuidades aerodinámicas críticas.

El uso de impresión 3D en material PLA, con grosor de 1.75 mm, no introduce penalizaciones aerodinámicas relevantes a las velocidades analizadas. La imagen 1, muestra parte del proceso de diseño CAD de la ojiva.

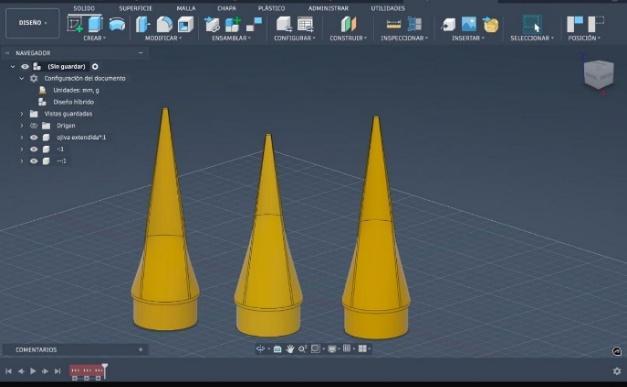
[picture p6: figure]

Imagen 1: Primeros bocetos de la ojiva biomimética

A continuación, se describe el análisis estático y de frecuencias modales para la ojiva.

En primera instancia, la Imagen 2 muestra como el factor de seguridad antes descrito, es superado por este modelo. La relación de seguridad acorde al material de fabricación implementado (PLA, 3-1), según el análisis de esfuerzo estático es superado por una relación de 4-1. Lo que refleja que el PLA es óptimo para el desarrollo de cohetes experimentales.

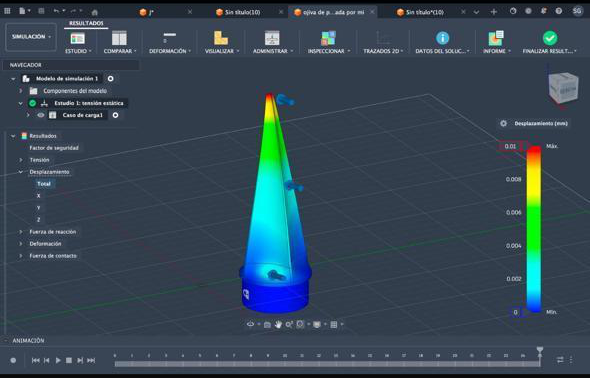
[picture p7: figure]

Imagen 2: Análisis de tensión estática, desplazamiento

Por su parte, la Imagen 2, indica el siguiente paso del desplazamiento estructural dentro de los parámetros mecánicos del material implementado, deformación del material. Los resultados indican que el diseño estructural de la ojiva es funcional y no repercute en la aerodinámica del cohete durante toda la trayectoria de vuelo que el proyectil ejecuta.

La Imagen 3, refleja el estudio de vibraciones modales aplicado a la masa integral del cuerpo. Donde se obtuvieron valores superiores a los establecidos cuando la frecuencia de entrada es de 0 Hz, es decir, el cohete aún no sufre desplazamiento vertical.

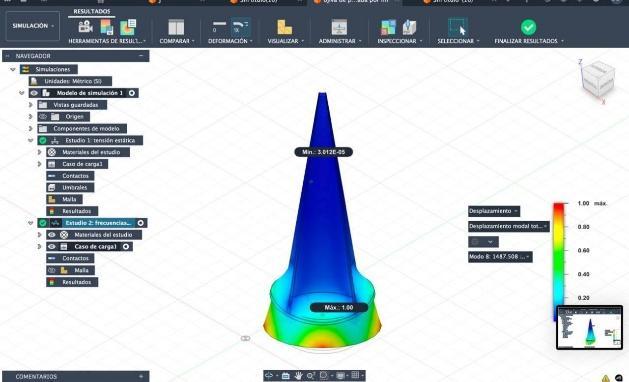
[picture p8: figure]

Imagen 3: Análisis de frecuencias modales

Enseguida, la Imagen 4 hace referencia al análisis de deformación mecánica, el cual comienza con el desplazamiento transversal de una fracción de la estructura externa del cuerpo analizado. Donde se ve claramente en la imagen como existe una deformación clásica para materiales del tipo ácido poliláctico. Al aplicar una carga estándar en una sección del cuerpo cónico-paraboloide, la estructura tiende a deformarse alcanzado la zona de elongación (zona amarilla) dentro de las características mecánicas del filamento de PLA.

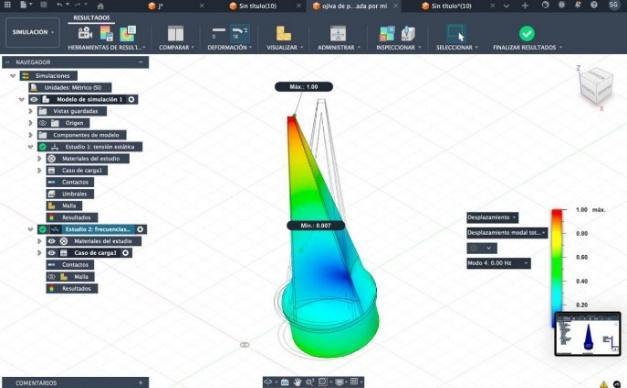
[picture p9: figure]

Imagen 4: Análisis de deformación mecánica

Con los resultados obtenidos, se decidió implementar la fabricación digital de este primer prototipo. La Imagen 5 refleja parte del proceso final de la impresión 3D. La ojiva en cuestión tiene una longitud total de 134.5 mm y un diámetro base de 50.2 mm.

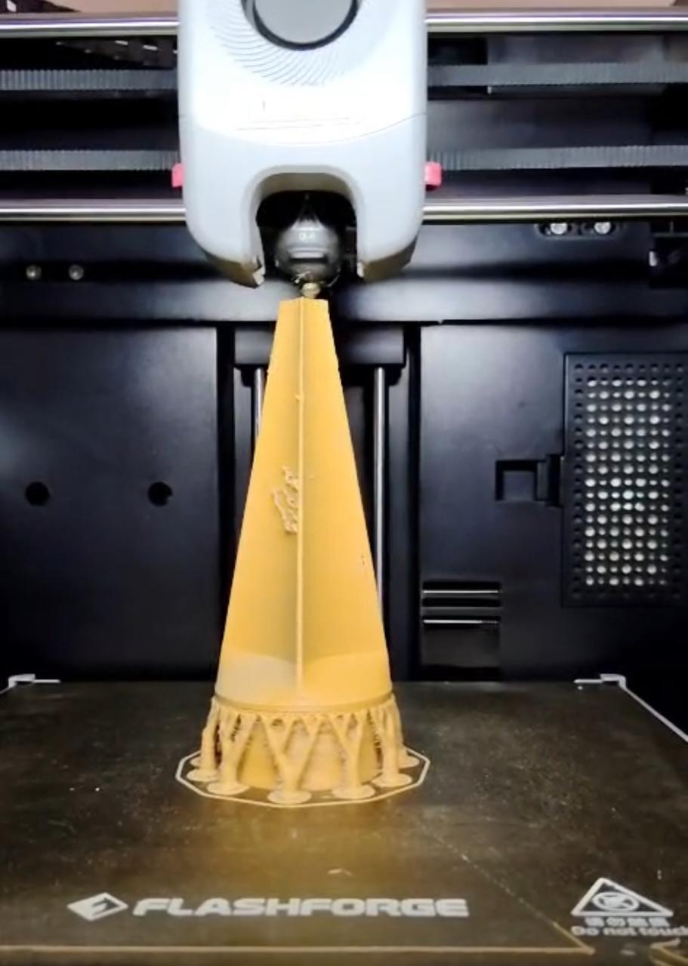
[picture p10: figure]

Imagen 5: Diseño del prototipo final

En la Imagen 6 se observa el nuevo diseño para la base del segundo prototipo, que es en forma de rombo, el cual estará contenido dentro del cilindro que se ajusta al fuselaje del cohete. Este diseño se integra de forma orgánica a la estructura física de ojiva Alcedo atthis; mitigando por completo el daño estructural del primer boceto.

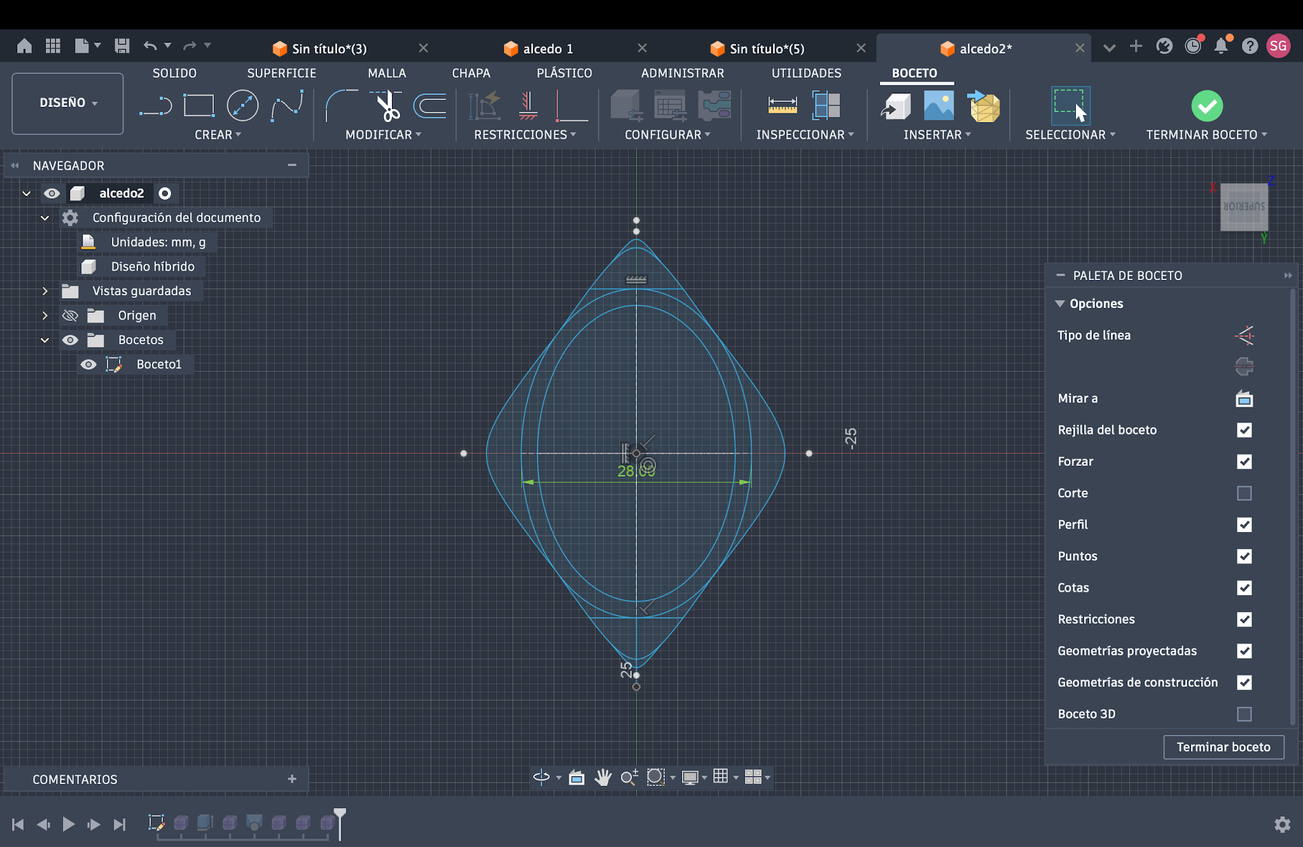
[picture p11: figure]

Imagen 6: Mejoramiento de la base, nuevo diseño

Además, se dio más longitud a la parte final de la ojiva, replicando de mejor forma la estructura ósea del pico del Martín pescador, lo que brindará mejor aerodinámica al entra en contacto con las fuerzas cortantes del viento.

La Imagen 7 evidencia el ajuste realizado a la punta de la ojiva.

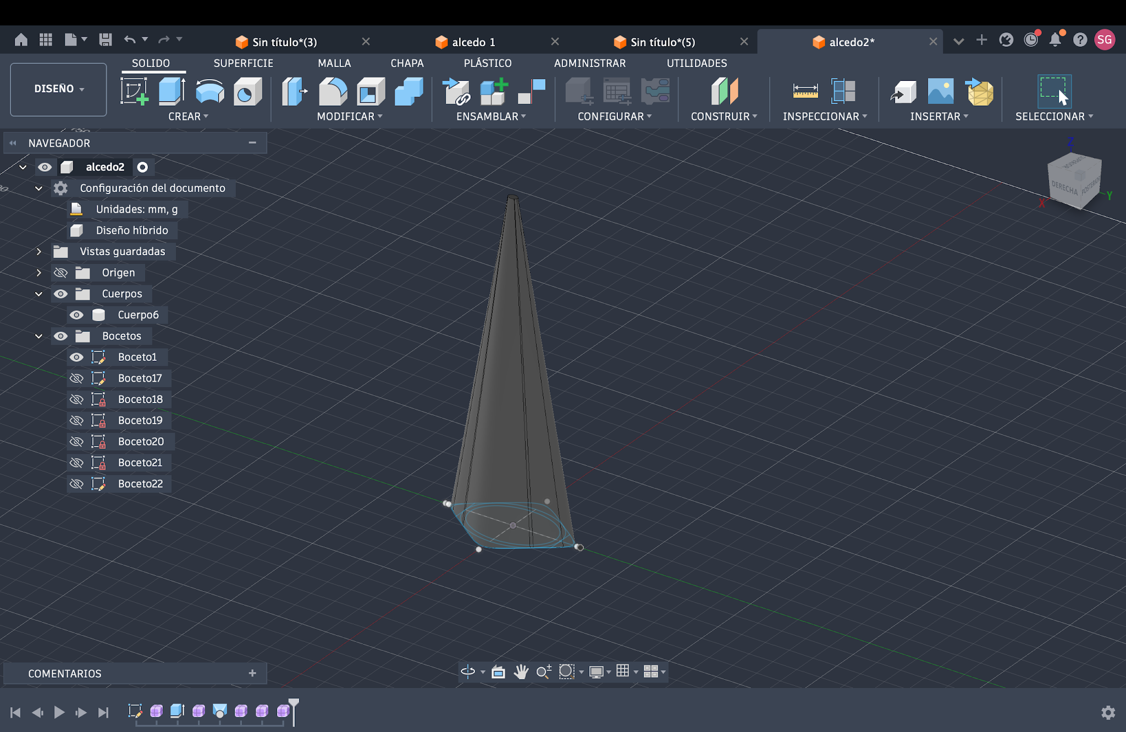
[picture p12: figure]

Imagen 7: Ajuste de la punta, nuevo diseño

Por último, la Imagen 8 revela la estructura aerodinámica final de la propuesta de ojiva Alcedo atthis.

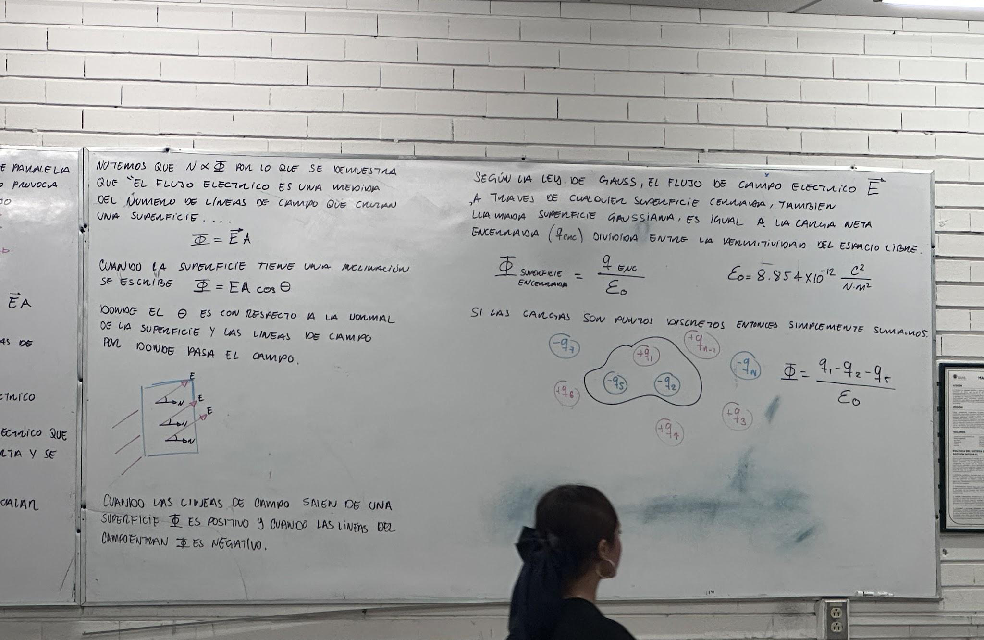
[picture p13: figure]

Imagen 8: Segundo prototipo terminado

9. DISCUSION

Los resultados obtenidos durante el desarrollo del proyecto evidencian que la implementación de principios biomiméticos en el diseño de ojivas para cohetería experimental posee un potencial significativo para mejorar el desempeño aerodinámico y estructural del sistema.

El análisis geométrico preliminar mostró que la configuración inspirada en el pico del Martín pescador presenta una transición progresiva entre la punta y el cuerpo principal de la ojiva, favoreciendo la continuidad superficial y disminuyendo zonas abruptas susceptibles a generar separación prematura del flujo. Este comportamiento coincide con lo señalado por Hoerner (1965), quien establece que las superficies con transiciones suaves reducen la formación de turbulencias y mejoran el comportamiento aerodinámico en regímenes subsónicos.

Durante el modelado CAD se identificó que la geometría biomimética permite un perfil longitudinal más estilizado respecto a configuraciones cónicas convencionales, lo cual puede favorecer una redistribución más uniforme de la presión dinámica alrededor de la superficie externa del cohete. Anderson (2016) sostiene que las geometrías aerodinámicas con perfiles progresivos contribuyen a minimizar el arrastre de presión, especialmente en vehículos de alta relación longitud-diámetro.

Los análisis estructurales realizados mediante Autodesk Fusion 360 indicaron que el material PLA utilizado en la fabricación del prototipo presenta un comportamiento mecánico favorable para aplicaciones de cohetería experimental de baja y media potencia. El factor de seguridad superior a 4:1 obtenido en el análisis estático demuestra que la estructura posee resistencia suficiente frente a las cargas previstas durante el ascenso del vehículo. Estos resultados son consistentes con investigaciones sobre manufactura aditiva aplicada a prototipos aeroespaciales, donde el PLA ha mostrado adecuada estabilidad estructural y facilidad de fabricación para aplicaciones experimentales (Blikstein, 2013).

Asimismo, los análisis modales revelaron frecuencias naturales superiores a las condiciones iniciales de excitación, sugiriendo que la estructura posee capacidad para tolerar vibraciones mecánicas preliminares sin comprometer su integridad física. Este aspecto resulta relevante debido a que las vibraciones aerodinámicas pueden influir negativamente en la estabilidad del vuelo y en la integridad del fuselaje (Fortescue et al., 2011).

Un hallazgo importante del proceso experimental fue la identificación de una debilidad estructural en la base del primer prototipo impreso. La observación física permitió detectar posibles zonas de fractura asociadas a concentración de esfuerzos mecánicos en la unión entre la ojiva y el fuselaje. Como respuesta, se implementó un rediseño geométrico basado en una estructura interna de tipo romboidal integrada orgánicamente al perfil biomimético. Esta modificación incrementó la resistencia mecánica del sistema y mejoró el acoplamiento estructural del conjunto.

La necesidad de realizar iteraciones de diseño confirma lo señalado por Versteeg y Malalasekera (2007), quienes destacan que los procesos de optimización aerodinámica requieren ajustes progresivos derivados de la interacción entre simulación computacional, análisis estructural y validación experimental.

Además, el ajuste longitudinal realizado en la segunda versión de la ojiva permitió aproximarse con mayor fidelidad a la morfología del pico del Martín pescador, favoreciendo un perfil más alargado y progresivo. Este aspecto adquiere relevancia debido a que Nakatsu (2009) demostró que la geometría inspirada en dicha ave puede reducir perturbaciones aerodinámicas y optimizar el desplazamiento de vehículos en medios fluidos.

Aunque los resultados obtenidos hasta el momento corresponden principalmente a análisis geométricos y estructurales

preliminares, la investigación evidencia que la biomimética constituye una línea viable para el desarrollo de soluciones innovadoras en cohetería experimental. No obstante, será indispensable realizar futuras simulaciones CFD, pruebas en túnel de viento y vuelos instrumentados para validar cuantitativamente el comportamiento aerodinámico de la propuesta y determinar con precisión el impacto de la geometría biomimética sobre el coeficiente de arrastre del vehículo.

En términos generales, los resultados obtenidos respaldan parcialmente la hipótesis de investigación, debido a que la ojiva bio-inspirada mostró características geométricas y estructurales favorables que podrían traducirse en mejoras aerodinámicas durante futuras etapas de validación experimental.

10. CONCLUSIONES

La presente investigación permitió desarrollar una propuesta innovadora de ojiva biomimética inspirada en la morfología del pico del Martín pescador aplicada a cohetería experimental de baja y media potencia, integrando principios de aerodinámica, biomimética, modelado CAD y manufactura digital.

Los resultados preliminares obtenidos evidencian que la geometría bio-inspirada presenta características favorables relacionadas con continuidad superficial, transición progresiva y potencial reducción de perturbaciones aerodinámicas, aspectos fundamentales para disminuir el arrastre en vehículos subsónicos experimentales.

El modelado tridimensional realizado mediante Autodesk Fusion 360 permitió reproducir de manera funcional las características morfológicas principales del pico del Martín pescador, facilitando además procesos iterativos de optimización geométrica y estructural.

Por otra parte, los análisis estáticos y modales demostraron que el material PLA posee condiciones mecánicas adecuadas para la fabricación inicial de prototipos experimentales, mostrando factores de seguridad favorables y estabilidad estructural frente a cargas preliminares.

Asimismo, la fabricación física del primer prototipo permitió identificar áreas de mejora relacionadas con la unión estructural entre la ojiva y el fuselaje, lo cual condujo al rediseño y fortalecimiento de la base estructural del sistema. Este proceso confirmó la importancia de integrar validación física dentro de los procesos de diseño aeroespacial experimental.

La investigación también evidenció que la biomimética representa una estrategia viable para el desarrollo de soluciones innovadoras en ingeniería aeroespacial educativa, particularmente en proyectos de cohetería experimental orientados a contextos STEM y divulgación científica.

Finalmente, se concluye que la propuesta posee potencial para evolucionar hacia futuras etapas de simulación CFD, pruebas en túnel de viento y vuelos instrumentados que permitan validar cuantitativamente su desempeño aerodinámico. De esta manera, el proyecto establece bases metodológicas y científicas para el estudio de perfiles biomiméticos aplicados al diseño de componentes aeroespaciales experimentales.

11. FUTURAS LÍNEAS DE INVESTIGACIÓN

El presente proyecto representa una fase inicial dentro del desarrollo de soluciones biomiméticas aplicadas a la cohetería experimental. Aunque los resultados preliminares se centran en el diseño geométrico y análisis conceptual de la ojiva bio-inspirada, la investigación abre múltiples posibilidades de profundización científica y tecnológica orientadas a validar experimentalmente el comportamiento aerodinámico del sistema y ampliar sus aplicaciones dentro del ámbito aeroespacial.

A continuación, se describen las principales líneas de investigación futuras derivadas del proyecto:

1. Simulación CFD de flujo aerodinámico

Una de las etapas prioritarias consiste en realizar simulaciones mediante Dinámica de Fluidos Computacional (CFD) para analizar cuantitativamente el comportamiento del flujo alrededor de la ojiva bio-inspirada. Estas simulaciones permitirán:

- Calcular el coeficiente de arrastre aerodinámico (Cd).
- Visualizar líneas de flujo y zonas de turbulencia.
- Identificar regiones de separación de capa límite.
- Comparar el desempeño frente a ojivas cónicas y ogivales.
- Analizar distribuciones de presión y velocidad.

La simulación CFD proporcionará evidencia cuantitativa para validar la hipótesis del proyecto y optimizar geométricamente el diseño.

2. Fabricación de prototipos mediante impresión 3D

Posteriormente, se contempla la fabricación física de las ojivas utilizando tecnologías de manufactura aditiva como impresión 3D FDM y SLA. Esta etapa permitirá evaluar:

- Precisión geométrica del diseño.
- Viabilidad de manufactura.
- Resistencia estructural.
- Compatibilidad con fuselajes de cohetes experimentales.

Además, la impresión 3D facilitará la producción rápida de variantes paramétricas para posteriores análisis comparativo.

3. Ensayos experimentales en túnel de viento

Como parte del proceso de validación experimental, se propone desarrollar pruebas en túneles de viento subsónicos de baja velocidad con el propósito de medir:

- Fuerzas reales de arrastre.
- Comportamiento del flujo.
- Estabilidad aerodinámica.
- Formación de turbulencias.

Estas pruebas permitirán contrastar los resultados obtenidos mediante simulación CFD con datos físicos reales, fortaleciendo la confiabilidad científica del proyecto.

4. Optimización paramétrica de la geometría biomimética

Otra línea de investigación relevante consiste en implementar procesos de diseño paramétrico para optimizar la geometría de la ojiva mediante variaciones controladas en:

- Relación longitud-diámetro.
- Curvatura superior e inferior.
- Radio de transición.
- Ángulo de afinamiento.
- Perfil frontal.

El uso de algoritmos de optimización geométrica podría permitir identificar configuraciones de mínimo arrastre dentro de la familia de perfiles inspirados en el Martín pescador.

5. Vuelos experimentales instrumentados

Una de las fases más importantes será la implementación de vuelos reales utilizando cohetes experimentales instrumentados con:

- Altímetros.
- Acelerómetros.
- Sensores IMU.
- Sistemas de telemetría.
- Cámaras de alta velocidad.

Estas pruebas permitirán medir variables reales de desempeño, tales como:

- Altitud máxima alcanzada.
- Estabilidad durante el ascenso.
- Velocidad máxima.
- Comportamiento dinámico.
- Eficiencia aerodinámica global.

La comparación experimental entre distintas geometrías permitirá validar de manera integral la funcionalidad de la propuesta biomimética.

6. Estudios de estabilidad y centro de presión

Debido a que la ojiva influye directamente en la posición del centro de presión del cohete, futuras investigaciones deberán evaluar:

- Margen de estabilidad.
- Relación entre centro de masa y centro de presión.
- Estabilidad estática y dinámica.
- Efectos de vibración aerodinámica.

Estos análisis serán fundamentales para garantizar seguridad y eficiencia durante vuelos reales.

12. LITERATURA CONSULTADA

Autodesk Inc. (2024). Fusion 360 user documentation and simulation tools. Autodesk.

ACARE. (2011). Flightpath 2050: Europe’s vision for aviation. European Commission.

Anderson, J. D. (2016). Introduction to Flight. McGraw-Hill Education.

Barrowman, J. S. (1967). The practical calculation of the aerodynamic characteristics of slender finned vehicles. Catholic University of America.

Benyus, J. M. (2002). Biomimicry: Innovation inspired by nature. HarperCollins.

Blikstein, P. (2013). Digital fabrication and ‘making’ in education. FabLabs: Of Machines, Makers and Inventors, 1–21.

Chiappe, A., & Lee, L. (2018). Open teaching: A new way on e-learning? Electronic Journal of e-Learning, 16(5), 369–383.

Fish, F. E., & Battle, J. M. (1995). Hydrodynamic design of the humpback whale flipper. Journal of Morphology, 225(1), 51–60. https://doi.org/10.1002/jmor.1052250105

Fortescue, P., Swinerd, G., & Stark, J. (2011). Spacecraft Systems Engineering. Wiley.

Freeman, S., Eddy, S., McDonough, M., Smith, M., Okoroafor, N., Jordt, H., & Wenderoth, M. (2014). Active learning increases student performance in science, engineering, and mathematics. PNAS, 111(23), 8410–8415.

Hoerner, S. F. (1965). Fluid-dynamic drag. Hoerner Fluid Dynamics.

Nakatsu, E. (2009). Bullet train nose. AskNature Innovation Database. Biomimicry Institute.

Niskanen, S. (2013). OpenRocket technical documentation release 13.05. OpenRocket.

Resnick, M. (2017). Lifelong Kindergarten. MIT Press.

Sutton, G., & Biblarz, O. (2017). Rocket Propulsion Elements. Wiley

NASA. (2022). NASA STEM Engagement Report. NASA (https://www.nasa.gov?utm_source=chatgpt.com)

Agencia Espacial Mexicana. (2023). Programas de divulgación científica y tecnológica. Agencia Espacial Mexicana (https://www.gob.mx/aem?utm_source=chatgpt.com)

ESA. (2022). Educational Space Programs. ESA (https://www.esa.int?utm_source=chatgpt.com)

Sampieri, R., Fernández, C., & Baptista, P. (2014). Metodología de la investigación. McGraw-Hill.

Versteeg, H., & Malalasekera, W. (2007). An introduction to computational fluid dynamics: The finite volume method (2nd ed.). Pearson Education.

Wang, Y., Zhao, K., Lu, X.-Y., Song, Y.-B., & Bennett, G. J. (2019). Bio-inspired aerodynamic noise control: A bibliographic review. Applied Sciences, 9(11), 2224. https://doi.org/10.3390/app9112224

13. ANEXOS

En Anexo A. Informe completo del estudio integral de la ojiva en el software Fusion 360 de Autodesk. Informe (https://drive.google.com/file/d/16lUyrXNOunfI0ILIMrZiqvOSO4KewQ0b/view?usp=sharing)

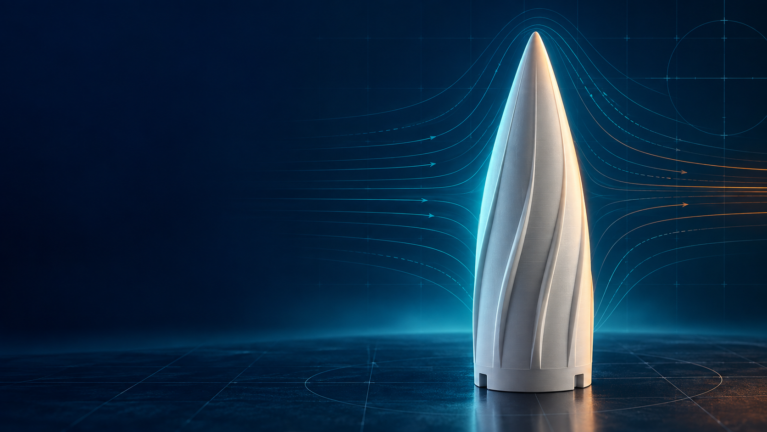
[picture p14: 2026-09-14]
assets/readme/ojiva-alcedo-hero.png

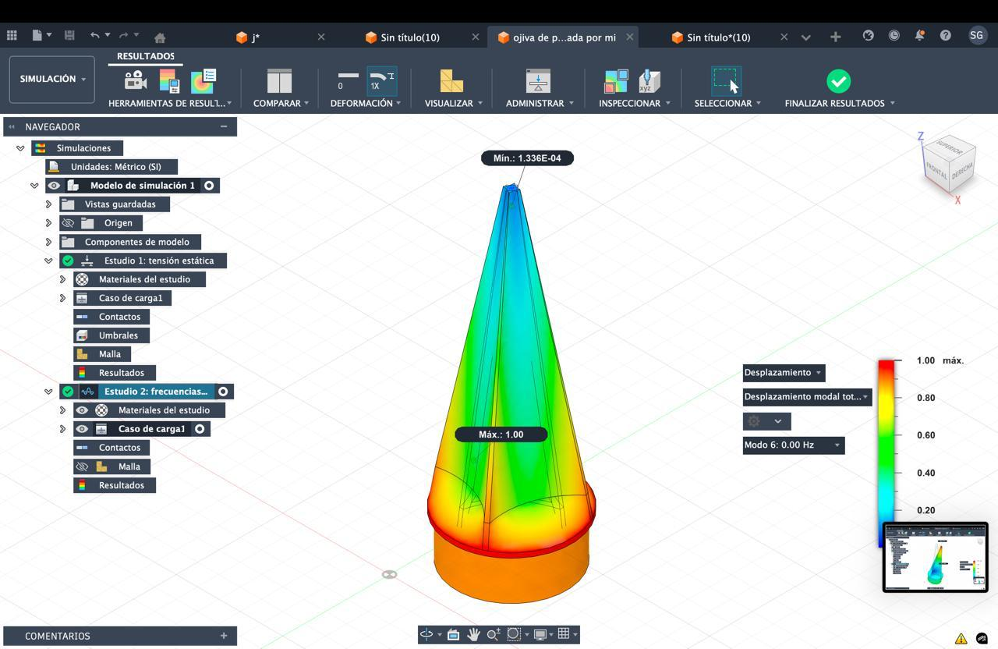
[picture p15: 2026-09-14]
media/simulation/06-modal-mode-6.png

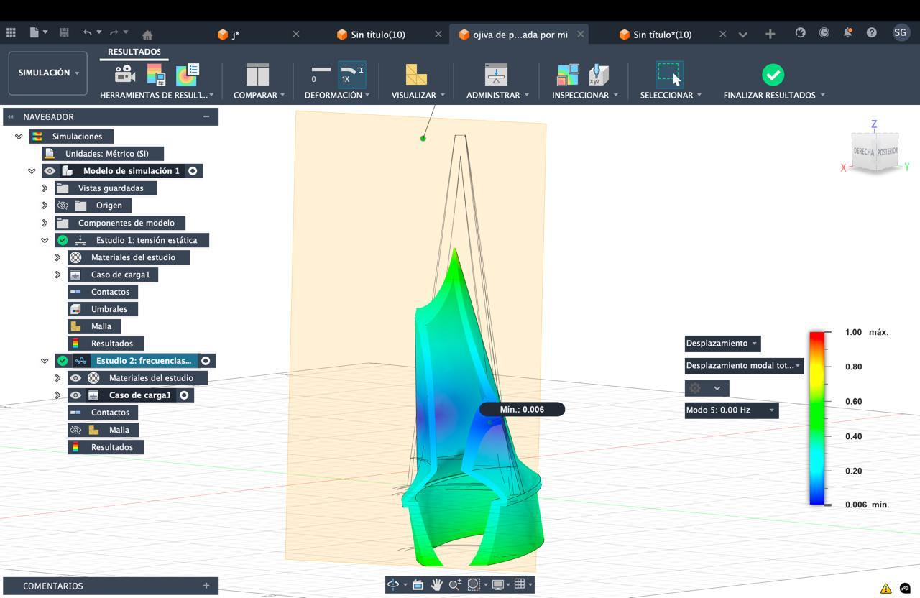
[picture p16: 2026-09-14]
media/simulation/04-modal-mode-5.png

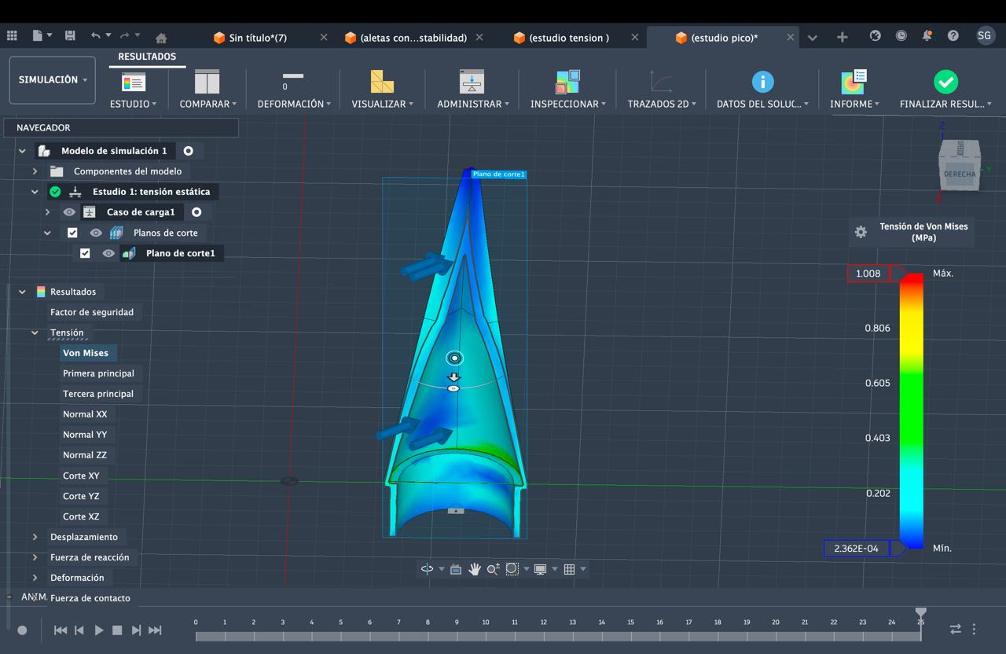
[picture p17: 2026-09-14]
media/simulation/01-static-von-mises-1.png

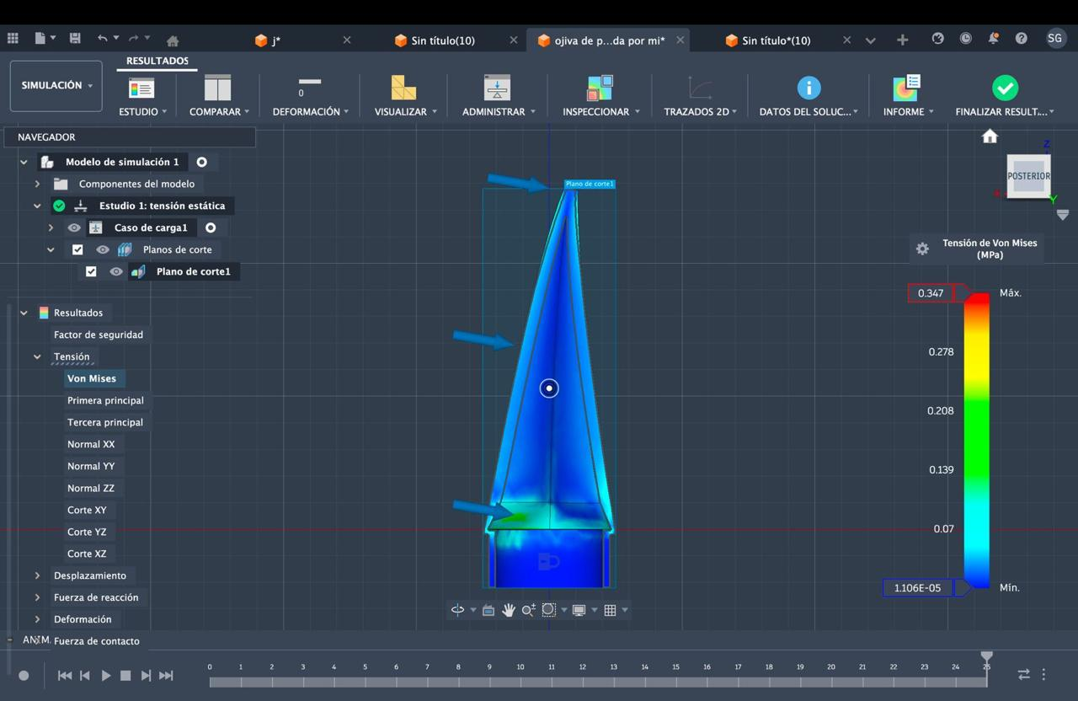
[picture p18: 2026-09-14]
media/simulation/08-static-von-mises-2.png

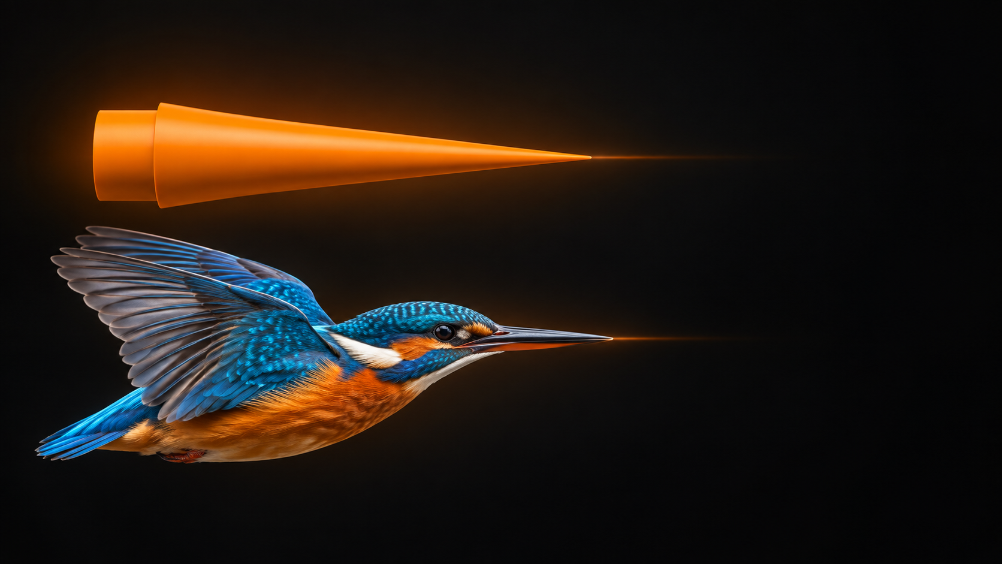
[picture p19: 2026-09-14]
assets/readme/ojiva-alcedo-hero-v2.png

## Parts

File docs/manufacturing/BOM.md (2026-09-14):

# Lista de materiales

Esta lista documenta el prototipo descrito en el informe fuente. No sustituye una seleccion de material basada en cargas y ambiente de vuelo.

| Elemento | Cantidad | Especificacion conocida | Estado |
| --- | ---: | --- | --- |
| Ojiva Alcedo atthis | 1 | STL o CAD de este repositorio | Incluido |
| Filamento PLA | Segun laminado | El informe indica PLA y grosor de 1.75 mm | Material de prototipo |
| Impresora 3D FDM | 1 | El informe menciona una impresora Creality | Equipo necesario |
| Fuselaje compatible | 1 | Diametro y tolerancia por confirmar | No incluido |
| Elementos de sujecion | Segun integracion | No especificados en el material fuente | Por definir |

## Datos que deben cerrarse antes de reproducir para vuelo

- Marca, grado y condicion de secado del filamento.
- Diametro nominal de filamento, ancho de pared, numero de perimetros, relleno y orientacion de impresion.
- Tolerancia del acople con el fuselaje y metodo de retencion.
- Masa impresa, centro de masa y acabado superficial.
- Material alternativo si se esperan temperatura, impacto o cargas superiores a las del prototipo PLA.

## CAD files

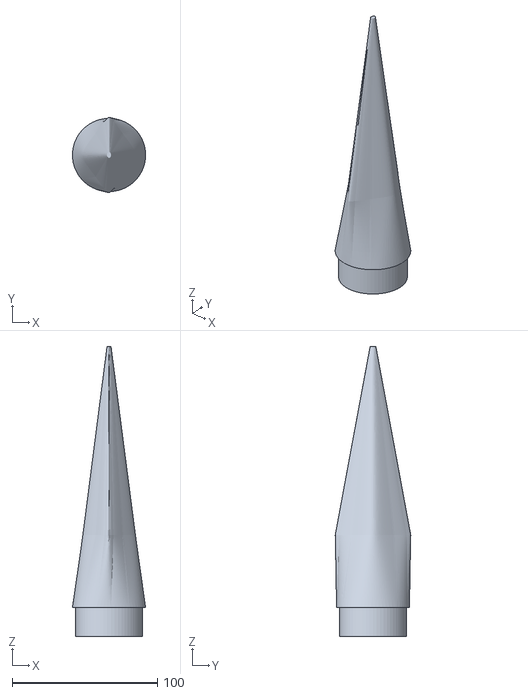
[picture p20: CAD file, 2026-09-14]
cad/mesh/ojiva-alcedo-atthis-v1.stl
50.5 x 52.1 x 200.0

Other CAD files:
cad/native/ojiva-alcedo-atthis-v1.f3d

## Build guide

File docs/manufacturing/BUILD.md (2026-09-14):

# Guia de fabricacion y control de calidad

## Antes de imprimir

1. Abra `cad/native/ojiva-alcedo-atthis-v1.f3d` en Fusion 360 y confirme que es la revision liberada.
2. Compare la longitud y los diametros con el fuselaje real. El STL v1 medido tiene 200 mm de altura de envolvente; el informe describe otro prototipo de 134.5 mm. No escale de forma automática sin resolver la discrepancia.
3. Revise la malla con un verificador de laminador. El STL es binario y contiene 12,948 triangulos; este repositorio no declara aun una verificacion de estanqueidad de malla.

## Impresion de prototipo

El informe fuente documenta un prototipo en PLA. No proporciona perfil de laminado suficiente para reproducibilidad, por lo que los siguientes parametros deben registrarse por quien fabrique una unidad:

- Laminador, version y unidades.
- Altura de capa, boquilla, perimetros, tapas y relleno.
- Orientacion, soportes, temperatura de boquilla/cama y velocidad.
- Material, lote y masa final.

La orientacion, el numero de perimetros y la union con el fuselaje afectan directamente la resistencia. Haga una prueba de ajuste en seco antes de integrar la pieza.

## Inspeccion

- Mida longitud total, diametro maximo y diametro/interferencia de la base.
- Examine paredes, punta, transiciones y base en busca de separacion de capas, huecos o grietas.
- Compruebe el ajuste con el fuselaje sin forzar la pieza.
- Registre masa, fotos y revision del archivo en un registro de fabricacion.

## Integracion y seguridad

No se incluyen instrucciones de propulsion ni de lanzamiento. Antes de usar una pieza en un vehiculo, evalúe la estabilidad completa, retencion, sistema de recuperacion, cargas esperadas, reglamentacion local y el protocolo de seguridad del sitio de prueba. Una pieza impresa en PLA puede cambiar sus propiedades con temperatura, envejecimiento y orientacion de capas.

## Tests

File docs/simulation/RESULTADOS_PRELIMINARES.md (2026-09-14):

# Evidencia de simulacion estructural preliminar

Las capturas en `media/simulation/` proceden de Autodesk Fusion 360 y se preservan como evidencia visual del estudio fuente. No se han proporcionado el archivo de estudio, material exacto, cargas, restricciones, malla ni reportes exportados; por ello los valores son **indicativos de las capturas**, no un caso reproducible.

## Resultados visibles

| Evidencia | Lectura visible | Interpretacion permitida |
| --- | --- | --- |
| `01-static-von-mises-1.png` | Von Mises maximo 1.008 MPa | Resultado de un estudio estatico mostrado; faltan condiciones de carga y material para validar el factor de seguridad. |
| `07-static-displacement.png` | Desplazamiento total maximo 0.01 mm | Resultado estatico mostrado; no debe extrapolarse a condiciones de vuelo. |
| `08-static-von-mises-2.png` | Von Mises maximo 0.347 MPa | Segundo resultado mostrado con diferentes condiciones no documentadas. |
| `02` a `06` | Formas modales normalizadas | Son visualizaciones de modos. Las escalas de desplazamiento normalizado no representan deformacion real. La captura `05` muestra 1487.508 en la interfaz, pero sin unidades o configuracion exportada no se registra como frecuencia validada. |

## Lo que no esta demostrado aun

- Reduccion de Cd frente a cono, parabola u ojiva tangente.
- Comportamiento en CFD reproducible.
- Resistencia con material, orientacion y cargas de vuelo definidas.
- Respuesta modal con frecuencias y amortiguamiento validados.
- Desempeno en tunel de viento o vuelo instrumentado.

## Para convertir este expediente en evidencia reproducible

Publique el archivo de simulacion, propiedades mecanicas del filamento, contactos, restricciones, magnitud y direccion de cargas, malla y estudio de convergencia. Para una afirmacion aerodinamica, anada geometria de referencia, configuracion CFD completa y datos comparativos de Cd con incertidumbre.

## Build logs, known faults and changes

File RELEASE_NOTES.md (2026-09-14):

# Notas de version

## v1.1.6 - 2026-09-14

- Actualiza la imagen de portada para que la ojiva completa y el pico del martín pescador se muestren grandes, paralelos y legibles.

## v1.1.5 - 2026-09-14

- Añade al final de ambos README la sección de equipo con autoras de la investigación y asesor.

## v1.1.4 - 2026-09-14

- Elimina el icono y el encabezado redundantes que aparecían antes de la portada; se conservan los controles de idioma.

## v1.1.3 - 2026-09-14

- Recompone la portada con la jerarquía visual de una tarjeta técnica: bloque de inspiración STL–pico a la izquierda, título y ficha de proyecto a la derecha.
- Mantiene al martín pescador en vuelo y la ojiva de base lisa, sin soportes temporales de impresión.

## v1.1.2 - 2026-09-14

- Mejora la composición de portada: la ojiva derivada del STL y el pico del martín pescador en vuelo están alineados en paralelo para hacer visible la referencia biomimética.
- Conserva exclusivamente la base cilíndrica lisa de la geometría publicada, sin soportes ni elementos temporales de impresión.

## v1.1.1 - 2026-09-14

- Sustituye la portada del README por una composición naranja y negra basada en la geometría del STL publicado.
- Muestra la ojiva completa, limpia y sin los soportes temporales de impresión; incorpora un martín pescador (*Alcedo atthis*) en vuelo como referencia biológica.

## v1.1.0 - 2026-09-14

- Anade portada e icono originales para el repositorio.
- Anade `README.es.md` y botones visibles para alternar entre ingles y espanol.
- Reestructura el README en ingles como punto de entrada internacional sin modificar el CAD ni la evidencia tecnica.

## v1.0.1 - 2026-09-14

- Anade un indice de licencias en la raiz para hacer visible la asignacion dual de CERN-OHL-W-2.0 y CC-BY-SA-4.0.
- Actualiza el expediente OSHWA para que apunte a la revision inmutable mas reciente.

## v1.0.0 - 2026-09-14

Primera liberacion publica del diseno de ojiva biomimetica Alcedo atthis.

- Publica CAD nativo Fusion 360 y STL para fabricacion.
- Incluye documento de investigacion en DOCX y PDF.
- Organiza las capturas disponibles de analisis estatico y modal.
- Anade guia de fabricacion, BOM, licencias CERN-OHL-W-2.0 y CC-BY-SA-4.0, y expediente OSHWA.
- Declara explicitamente los limites de validacion y la discrepancia dimensional pendiente.

No se declara certificacion OSHWA ni una mejora cuantitativa de arrastre en esta version.

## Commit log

2026-09-14 Initial open hardware release v1.0
    [ojiva-alcedo-atthis-v1.f3d, ojiva-alcedo-atthis-v1.stl]
2026-09-14 Use STL-based ojiva hero with flying kingfisher
2026-09-14 Align STL ojiva hero with kingfisher beak
